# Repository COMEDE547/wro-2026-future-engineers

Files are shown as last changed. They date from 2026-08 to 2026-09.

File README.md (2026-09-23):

# WRO Future Engineers 2026 — Engineering Materials

Engineering documentation for an autonomous vehicle built for the **World Robot
Olympiad Future Engineers** category, season **2026**.

> **Team:** TED drive · **Members:** Ethan Fernandes (software) · Tejas Sirikonda (mechanical) · Deeyan Mehta (electronics) · **Coach:** Amey Chavan (OMOTEC) · **Country:** India

> **Vehicle status (2026-09-22):** the car was rebuilt in September for APAC 2026; what changed is in [`docs/apac_2026_vehicle.md`](docs/apac_2026_vehicle.md), and the code it runs is in [`src/apac-2026/`](src/apac-2026/). The At-a-glance table and documents 1–5 below describe the Nationals (August 2026) configuration.

**Contents:** [At a glance](#at-a-glance) · [Documentation index](#documentation-index) · [Repository layout](#repository-layout) · [Quick start](#quick-start) · [Competition artifacts](#competition-artifacts) · [Version history](#version-history) · [Known limits](#known-limits) · [Licence](#licence)

---

## At a glance

| | |
|---|---|
| **Architecture** | Two processors. ESP32 runs sensing and steering at ~50 Hz (nominal; effective rate unmeasured); Raspberry Pi 5 runs pillar detection. A stalled detector cannot stall the steering loop. |
| **Steering** | Single-servo Ackermann, 64-136 deg travel about a 106 centre (asymmetric, mat-tuned 2026-08-10), proportional on heading error at 1.0 servo-deg/deg with a 2 deg deadband — saturating at 42/30 deg of error |
| **Heading** | BNO055 absolute yaw. Corner detection is a *rising-edge* test on a side TF-Luna crossing 150 cm |
| **Range sensing** | 3x TF-Luna behind a PCA9548A I2C multiplexer (all three share address `0x10`) |
| **Pillar detection** | **Calibrated-Lab colour picker** — one (a,b) chroma disc per colour, sampled at the venue; the prior neural stack was superseded 2026-08-05 |
| **Why the neural stack lost** | `nanodet_lite` val decision accuracy **0.941** did not transfer to real footage — single-session, zero-clutter training data (a limit stated at training time, then observed) |
| **Validation** | 473 / 124 group-wise split, leakage-audited. 597 source images, **one lighting session**. |
| **Open Challenge** | Implemented — driven on the mat 2026-08-08/09 (test footage in [`other/`](other)); steering-sign fix + retune landed 2026-08-10 |
| **Obstacle Challenge** | ~~Implemented off-repo~~ **In-repo since 2026-08-06/07** — [`round2.py`](src/Round%202/round2.py) + [`main.cpp`](src/Round%202/main.cpp); radio compile-gated off (§11.10), I2C map verified (BNO on mux ch4) |
| **Drivetrain** | **Built and driven (final chassis — rebuild cancelled 2026-08-10)** — N20 via TB6612 through a LEGO differential; Ackermann steering. Pinion:crown counted 2026-08-11 (20:28 = 5:7); working-point currents still unmeasured. |

---

## Documentation index

Organised against the five criteria WRO uses to score engineering documentation.

| # | Criterion | Document | State |
|---|---|---|---|
| 1 | Mobility & Mechanical Design | [`docs/1_mobility.md`](docs/1_mobility.md) | Steering + drive integrated, driven on the mat, retune 2026-08-10 documented; **chassis final (rebuild cancelled 2026-08-10)**; pinion:crown counted 2026-08-11 on the vehicle: 20:28 = 5:7 |
| 2 | Power & Sensor Architecture | [`docs/2_power_and_sensors.md`](docs/2_power_and_sensors.md) | Sensors and camera geometry documented; **power budget partly measured** (pack voltage 2026-08-12, cruise current 2026-08-24; per-rail currents not yet) |
| 3 | Software Architecture & Obstacle Strategy | [`docs/3_software.md`](docs/3_software.md) | Open implemented (drives); Obstacle implemented, **in-repo since 2026-08-06/07**; Nationals competition stack at [`src/Round 2/competition/`](src/Round%202/competition/) since 2026-08-24; APAC 2026 code at [`src/apac-2026/`](src/apac-2026/) since 2026-09-22 |
| 4 | Systems Thinking & Engineering Decisions | [`docs/4_systems_and_decisions.md`](docs/4_systems_and_decisions.md) | Decision log, rejected alternatives, risk register |
| 5 | Reproducibility & Repository Quality | [`docs/5_reproducibility.md`](docs/5_reproducibility.md) | Reproduction steps, licensing, versioning policy |
| — | **APAC 2026 vehicle (September rebuild)** | [`docs/apac_2026_vehicle.md`](docs/apac_2026_vehicle.md) | Changes since Nationals, bench measurements (2026-09-21) and the code in [`src/apac-2026/`](src/apac-2026/); six-view photos, a full Obstacle Challenge run on video and the car's own test logs in [`docs/apac_2026_test_logs.md`](docs/apac_2026_test_logs.md) |
| — | **APAC 2026 software (Obstacle Challenge)** | [`docs/apac_2026_software.md`](docs/apac_2026_software.md) | State diagrams of `main.py`, the thresholds on each transition, why the states are split this way, edge cases and known limits |
| — | **Engineering Journal (APAC 2026)** | [`docs/engineering_journal_apac_2026.pdf`](docs/engineering_journal_apac_2026.pdf) | 26 pp; the APAC vehicle, built from this repository's documents by [`docs/journal/build_apac_journal.py`](docs/journal/build_apac_journal.py). The Nationals journal is the next row |
| — | **Engineering Journal (final, rev 3)** | [`docs/engineering_journal_final.pdf`](docs/engineering_journal_final.pdf) | 26 pp; describes the Nationals (August 2026) competition configuration; matches the repository at `b715a4b` |
| — | Testing workflow | [`docs/tests.md`](docs/tests.md) | T1-T4 running; T5-T7 blocked on hardware |
| — | Detector reference | [`src/Round 2/detector/README.md`](src/Round%202/detector/README.md) | Results, operating point, reproduction |
| — | Firmware reference | [`src/README.md`](src/README.md) | Sketch-by-sketch |

**Start with [4 — Systems Thinking](docs/4_systems_and_decisions.md)** if you only
read one. It carries the decision log, including the alternatives that were built
and rejected and the numbers that killed them.

---

## Repository layout

```
docs/           five criterion documents + testing workflow + figure scripts
src/Round 1/    ESP32 firmware — heading hold, corner detection, steering
src/Round 2/    flight stack (round2.py + main.cpp + eval harness) + superseded detector (kept as evidence) + classical HSV pipeline
models/         CAD / printable parts        — team STLs (TF-Luna enclosure, steering horn, N20 clamp) + current chassis LEGO design + 69-step build instructions; third-party mounts cited, not redistributed
schemes/        electromechanical schematics — signal + power wiring v0.2 (generated)
t-photos/       team photos                  — official team photo present (Ch.7 requires one)
v-photos/       vehicle photos               — 6 views, refreshed 2026-08-11 (redesigned frame, Pi + camera mounted); APAC 2026 six views in apac-2026-09-22/
video/          performance video links      Open 33 s + Obstacle 100 s (YouTube); APAC Obstacle run (mp4)
other/          datasheets, setup notes
```

Empty directories are empty because the artifact does not exist yet, not because
it was overlooked. Each one says which.

---

## Quick start

**Run the superseded neural detector (kept runnable as iteration evidence):**

```bash
cd "src/Round 2/detector"
python decide_nanodet.py --camera 0 --window 5     # prints "left" or "right"
python decide_nanodet.py --image frame.jpg
python decide_nanodet.py --sweep                   # re-derive the operating point
```

**Reproduce every number in this repository from scratch:**
see [`docs/5_reproducibility.md`](docs/5_reproducibility.md#3-reproducing-the-detector-from-zero).

**Build and flash the firmware:** Arduino IDE or PlatformIO, board = ESP32.
Libraries: Adafruit BNO055, Adafruit Unified Sensor, Adafruit BusIO, ESP32Servo.

---

## Competition artifacts

| Artifact | Required | Status |
|---|---|---|
| 6 vehicle photos — every side, top and bottom | Yes | **Present** — Nationals vehicle: `v-photos/` (2026-08-11, redesigned frame with Pi 5 and camera); APAC 2026 vehicle: [`v-photos/apac-2026-09-22/`](v-photos/apac-2026-09-22/) (2026-09-22, six views, side rollers removed). The 2026-08-11 set replaced a 2026-08-05 set that showed the pre-redesign chassis |
| Team photo | Yes | **Present** — `t-photos/team_photo_official.jpg`. Chapter 7 requires "a team photo" (singular); the informal second photo, a template convention rather than a rule, is `t-photos/team_photo_informal.jpg` |
| Performance video, >= 30 s autonomous driving, one per challenge | Yes | **Present**: Open Challenge 33 s and Obstacle Challenge 100 s on YouTube, in [`video/video.md`](video/video.md); additional footage of the APAC vehicle (a full Obstacle Challenge run, 3 min 19 s) in the same folder |
| Electromechanical schematic | Yes | **Present** — signal + power wiring v0.2 in `schemes/` (generated by a committed script; remaining unknowns drawn as TBD) |
| Control software | Yes | Present, `src/` |
| CAD / printable parts | Yes | **Present 2026-08-11/12** — team STLs (TF-Luna enclosure ×3-printed, steering horn, N20 clamp) + the **current chassis LEGO design file** and its 69-step build instructions in `models/chassis/`; camera-mount kit is third-party, cited not redistributed; MG90 is LEGO-integrated (no printed mount); no chassis STL because the redesign was in LEGO, not print (see D8) |

The pending rows are tracked here so the gap is visible rather than discovered
late.

---

## Version history

| Version | Date | Change | Problems it created or exposed |
|---|---|---|---|
| — | 2026-06-26 | Initial repo; ESP32 firmware — IMU heading hold, TF-Luna corner detection, ultrasonic prototype | Corner detection needed a rising-edge test; a level test re-fires and spins the vehicle |
| — | 2026-07-19 | HSV pillar pipeline v4.1, 0.43 ms/frame | Measured to fail in **both** directions, which voided the planned ROI-verifier fallback |
| — | 2026-07-26 | Trained NanoDet-Plus detector; vision moved under `Round 2` | Validation split found contaminated — 25 duplicate stems, 27/29 shared capture buckets. All prior numbers withdrawn and re-measured on a clean 473/124 split. |
| — | 2026-07-28 | Documentation restructured against the five scoring criteria | Root README had described the vehicle as camera-free after the detector had shipped |
| — | 2026-08-05 | Drive integrated (N20 / TB6612, append-only); calibrated-Lab picker declared the Round 2 stack; NanoDet superseded after field testing; signal-wiring schematic v0.1 added | The val-split winner did not survive real footage — the single-session dataset limit, stated at training time, was observed in practice |

Full reasoning for each entry: [`docs/4_systems_and_decisions.md`](docs/4_systems_and_decisions.md).

---

## Known limits

Stated here rather than left for a reader to find.

- **Every detector number rests on 597 images from a single lighting session**,
  with no other robots, spectators, banners or reflective flooring present. The
  figures are indicative, not a venue prediction — and field testing subsequently
  observed exactly this transfer failure (see the version history).
- **Both-pillar figures are synthetic composites.** No real image in the dataset
  contains a red and a green pillar at once.
- **No Raspberry Pi 5 latency figure exists for this model.** It will not be
  quoted until `benchncnn` has run on the target board.
- ~~**The Obstacle Challenge controller is not yet in this repository.** It is
  implemented and bench-tested off-repo; it lands after integration fixes.~~
  **Landed 2026-08-06/07** (`src/Round 2/round2.py` + `main.cpp`); this bullet
  was stale until 2026-08-10. [`docs/3_software.md`](docs/3_software.md) remains
  the specification of record.
- **The camera is a USB UVC webcam** — a **Lenovo 300 FHD** (read off the unit 2026-08-11; **OMO/WCAM/11** is the team's label for it, first recorded
  2026-08-08); field-of-view and angular-resolution figures are still pending a
  checkerboard measurement, so none is quoted.
- ~~**The vehicle is built to Round-1 configuration.** The Raspberry Pi 5 and camera are not yet mounted.~~ Stale since 2026-08-11, when both were mounted (six-view photos).
  Drive bring-up (direction, duty, corner tests)
  ~~is unfinished~~ happened 2026-08-08/09; the chassis is final (rebuild
  cancelled 2026-08-10). That was the Nationals car; it was rebuilt for APAC 2026
  ([`docs/apac_2026_vehicle.md`](docs/apac_2026_vehicle.md)).

---

## Licence

MIT — see [`LICENSE`](LICENSE). `src/Round 2/detector/nanodet_lite/` is a
derivative of [NanoDet](https://github.com/RangiLyu/nanodet) and is Apache-2.0;
its licence is at `src/Round 2/detector/LICENSE-nanodet-Apache-2.0`.

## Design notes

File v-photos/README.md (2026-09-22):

# Vehicle photos

Six views as required by chapter 7 — every side, plus top and bottom — of the
vehicle **as it ran at Nationals**, photographed 2026-08-11. Working photos of the
September rebuild for APAC 2026 are in [`apac-2026-09-20/`](apac-2026-09-20/); the
six-view set of the APAC vehicle (received 2026-09-22) is in
[`apac-2026-09-22/`](apac-2026-09-22/) (table below).

| File | View | What it shows |
|---|---|---|
| `vehicle-front.jpg` | Front | Camera on its printed arm, the centre TF-Luna behind its orange bracket, front wheels (41 × 21 mm) |
| `vehicle-rear.jpg` | Rear | Electronics deck from behind, rear wheels (55.6 × 14 mm) through the differential |
| `vehicle-left.jpg` | Left | Full profile, nose to frame-right — deck height, camera standoff, side TF-Luna |
| `vehicle-right.jpg` | Right | Full profile, nose to frame-left |
| `vehicle-top.jpg` | Top | ESP32, buck converter, PCA9548A multiplexer and BNO055 on the deck |
| `vehicle-bottom.jpg` | Bottom | LEGO differential, drive shaft from the N20 pinion, steering linkage |
| `detail/` | — | Two close-ups: chassis mid-section, and the front sensor + camera mount |

Note on labels: in this set, `vehicle-left.jpg` shows the nose to frame-right,
which by the usual convention is the car's right side, and `vehicle-right.jpg`
shows its left side. The APAC photos in `apac-2026-09-20/` use the usual
convention.

## These replaced an earlier set, and why

The previous six photos were taken **2026-08-05** and showed the vehicle before
the chassis was redesigned. The wheel-shed failure of 2026-08-06 was answered by
a ground-up redesign of the LEGO space-frame — stiffer than the first layout —
and every run and every committed artifact since 2026-08-09 is on that frame
([1 — Mobility](../docs/1_mobility.md) §3,
[D8](../docs/4_systems_and_decisions.md)). Photographs of a superseded frame
would have described a vehicle that no longer exists, so they were replaced
rather than kept.

The 2026-08-05 set also predated the Pi 5 and camera being mounted; both are
fitted and visible here.

## APAC 2026 six-view set (2026-09-22)

The rebuilt vehicle ([APAC 2026 vehicle](../docs/apac_2026_vehicle.md)), photographed on
the team's practice mat after the horizontal side rollers were removed (photos
received 2026-09-22; §7 there). Usual convention: `apac-left.jpg` is the car's left side, nose to frame-left.

| File | View | What it shows |
|---|---|---|
| `apac-2026-09-22/apac-front.jpg` | Front | Camera on the rear tower, the WS2812 strips on the front frame, the centre TF-Luna in its orange bracket, front wheels |
| `apac-2026-09-22/apac-rear.jpg` | Rear | The tower from behind, the power switch, rear wheels |
| `apac-2026-09-22/apac-left.jpg` | Left | Full profile, nose to frame-left |
| `apac-2026-09-22/apac-right.jpg` | Right | Full profile, nose to frame-right |
| `apac-2026-09-22/apac-top.jpg` | Top | Camera housing over the deck, ESP32 board and breakouts, rear wheels |
| `apac-2026-09-22/apac-bottom.jpg` | Bottom | Underside with the car laid on its side: both axles and the drive motor |

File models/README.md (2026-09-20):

# models/ — CAD for TED drive (WRO FE 2026)

The vehicle is a **LEGO Technic chassis**; every non-LEGO component is held by a
3D-printed bracket. This folder holds the team's own design files and printable
parts. Third-party parts used on the vehicle are attributed below and NOT
redistributed here.

## Chassis — APAC 2026 frame (September rebuild)

| File | What it is |
|---|---|
| `chassis/chassis_build_instructions_apac_2026-09.pdf` | 84-step build instructions for the frame used at APAC 2026. LEGO parts only; the printed parts are the same STL files as at Nationals (listed below). |

What changed since Nationals: [`docs/apac_2026_vehicle.md`](../docs/apac_2026_vehicle.md).

## Chassis — Nationals frame (August 2026)

| File | What it is |
|---|---|
| `chassis/chassis_lego_current.lxfml` | The LEGO design for the frame the vehicle ran at Nationals — 91 elements, 19 distinct part types |
| `chassis/chassis_build_instructions.pdf` | 69-step build instructions generated from that model, enough to rebuild the frame from parts |

**This was the redesigned Nationals frame, not the superseded first layout.** The first layout could
not package motor and battery together, carried its mass too high, and would not
hold a curve; under drive load it also flexed enough to work the rear axle
interface loose, and the wheels shed within seconds on 2026-08-06. The answer was
a ground-up redesign of the space-frame, built stiffer — the frame documented
here. It ran 28 s and 29 s with no wheel loss on 2026-08-09, roughly six times
the failure duration, and the planned 3D-printed rebuild was cancelled as
unnecessary. Full account: [1 — Mobility](../docs/1_mobility.md) §3 and
[D8](../docs/4_systems_and_decisions.md).

Because the answer was a LEGO redesign rather than a printed one, the chassis
artifact here is a design file and a build sequence rather than a chassis STL.
There is no printed chassis and there never was.

## Team-designed printed parts (Nationals vehicle, as fitted 2026-08-11)

| Part | File | Fitted as | Bounding box (mm) | Designed by / in |
|---|---|---|---|---|
| TF-Luna holder | `tf-luna/TF_luna_enclosure_lego.stl` | LEGO-pitch face frame for a TF-Luna (56 mm = exactly 7 LEGO modules; printed 3×, orange PLA) | 9.0 × 56.0 × 26.3 | TED drive, Fusion 360 |
| Servo horn beam, long | `steering/Horn_Beam_LONG.stl` | MG90S horn → LEGO beam steering link | 45.5 × 11.8 × 7.8 | TED drive, Fusion 360 |
| N20 motor mount | `drive/n20_clamp_lego.stl` | Printed clamp holding the 12 V N20 gearmotor to the LEGO frame | 38.8 × 26.0 × 12.0 | TED drive, Fusion 360 (re-modelled; .f3d export still owed) |

Parametric sources: Fusion 360 — **export and commit the .f3d/.step for each
team part alongside its STL** (Fusion cloud retains them).

## Third-party printed parts — sources

The Lenovo 300 FHD webcam is held by four printed parts of a published mount
kit. The kit's files are linked, not redistributed, in this repository — that
is safe under every possible license, and attribution is the requirement
either way.

**[1]** cncplasticfactory, *"Lenovo 300 FHD Webcam Mount for 3D Printers with
2020 Extrusions,"* Printables.com, model 352447, updated 29 Dec 2022.
https://www.printables.com/model/352447 — accessed 11 Aug 2026.
Parts as fitted on the vehicle: front clamp, rear clamp, base bracket, spacer
arm (white PLA). License: stated on the model page (not machine-readable at
citation time) — confirm there before ever redistributing the files.
Parts used as-printed from the published geometry; no modifications.

**[2]** PsychoShaft, *"C92X Mount,"* VoronDesign/VoronUsers `printer_mods`
(the upstream design that [1] remixes).
https://github.com/VoronDesign/VoronUsers/tree/master/printer_mods/PsychoShaft/C92X_PsycHoShafts_Mount
— lineage credit only; no files taken from it directly.

**[3]** Lenovo, *"Lenovo 300 FHD WebCam — Overview and Service Parts,"*
acc500192.
https://support.lenovo.com/in/en/accessories/acc500192-lenovo-300-fhd-webcam-overview-and-service-parts
— the mounted camera hardware (1080p, 95° FOV, USB). Team designation for the
same unit: **OMO/WCAM/11** (see `docs/2_power_and_sensors.md`).

## Not printed

MG90S servo body is LEGO-integrated. The N20 sits in the printed clamp above;
the .f3d source for it is still owed.

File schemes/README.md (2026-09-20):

# Electromechanical schematics

**Current: [`wiring_apac_2026.md`](wiring_apac_2026.md)** — power and signal wiring of the September 2026 rebuild for APAC 2026 (WS2812 LEDs on GPIO4, power switch on the battery lead, start button on GPIO32, MEX drive motor), drawn as a Mermaid diagram that GitHub renders. The files below describe the Nationals (August 2026) vehicle.

**`wiring-v0.2.png` / `.pdf` — signal-wiring authority (2026-08-10); its power
tree is HISTORICAL, superseded by the 2026-08-11 rework recorded in the hand
diagram below.** Everything v0.1 drew, plus the power tree as identified on
2026-08-10: 3S 11.1 V pack (label read 2026-08-11: **2200 mAh 60C** — the
frozen v0.2 render predates the read and shows 2600) -> dual-rail buck
(barrel-jack in; XL4015/LM2596-class, chip and rating TBD; 5 V screw out +
USB-A out) -> ESP32 VIN, with the servo drawn through the ESP32's 5 V chain
(the named brownout risk in [docs/2 §5](../docs/2_power_and_sensors.md) —
**fixed 2026-08-11**: servo power moved to Buck-2; the v0.2 render predates
the rework), pack 11.1 V direct to TB6612 VM, and the buck's USB-A drawn as the
**candidate** Pi 5 supply — TBD, because a plain USB-A source has no PD
negotiation, which makes the Pi 5 cap its USB-peripheral budget at 600 mA.
Unknowns are drawn as TBD rather than guessed. The missing rule-9.10-mandatory
main power switch and the absent fuse are called out on-sheet.

The diagram is generated, not hand-drawn: edit
[`make_wiring_v0_2.py`](make_wiring_v0_2.py) and rerun
(`py -3 schemes/make_wiring_v0_2.py` from the repo root, needs matplotlib) —
do not edit the PNG.

**`wiring-signal-v0.1.png` / `.pdf`** — superseded 2026-08-10, retained as
history. Signal wiring only; left the power tree as "pending battery selection"
(the pack was read off the hardware on 2026-08-06) and carried a CH4-vs-CH5
BNO055 harness question that closed when the Round 2 firmware landed on
**CH4**.

**`circuit_diagram_complete_2026-08-11.jpg`** — full power + control diagram
(hand-drawn, photographed at the bench 2026-08-11). Companion to wiring-v0.2,
which remains the generated signal-wiring authority. Every firmware-relevant
pin on this diagram was cross-checked against `src/Round 2/main.cpp` the same
day and matched 6/6: I2C SDA/SCL `21/22`, servo `13`, TB6612 `25/26/33/27`,
PCA9548A `0x70` (channels 0/1/2 = TF-Luna `0x10`, CH4 = BNO055 `0x28`). It also
records the as-built power tree confirmed on the vehicle: servo **power** from
Buck-2 (signal only from the ESP32), 3× TF-Luna on Buck-2, ESP32 from a Pi USB
port, Pi via the fast-charging module — see `docs/2_power_and_sensors.md` §5/§6
for the rework note this supersedes. **Known omission:** the diagram does not
show the external start button on **GPIO32** that both firmwares use — the
button was wired after the diagram was drawn; treat GPIO32 as present per
`src/`.

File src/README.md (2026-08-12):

# Control software

Two rounds, two processors.

## `Round 1/` — ESP32 firmware

Compiles in the Arduino IDE or PlatformIO, board = **ESP32**. Each sketch sits in
its own folder, per Arduino IDE convention.

| Sketch | Role |
|---|---|
| `round 1/round 1.ino` | **Main driving firmware.** Captures a target heading from the BNO055, drives straight by proportionally counter-steering the servo to null heading error, and detects corners on the rising edge of a side TF-Luna crossing 150 cm (steps the target heading by 90 deg). Drives an N20 via TB6612 (append-only module): 20 kHz 10-bit PWM, observer turn counter, settle-gated 0.5 s run-on after 12 corners, then brake. Steering-sign fix + retune 2026-08-10 (`58adb1c`): center 106, limits 64/136, gain 1.0, DRIVE_SPEED 1000. |
| `motor_test/motor_test.ino` | Serial bring-up for the drive motor via `motor_control.h` (w/s speed steps, `r` reverse, `b` brake, `i` state). Pin constants matched to the main-firmware harness: PWM 33 · IN1 25 · IN2 26 · STBY 27. |
| `triple_ultrasonic_sensor/triple_ultrasonic_sensor.ino` | Standalone 3x HC-SR04 test (front / left / right), interrupt-driven and non-blocking. Alternative sensing prototype — see the LiDAR-vs-ultrasonic comparison in [`docs/2_power_and_sensors.md`](../docs/2_power_and_sensors.md#why-lidar-over-ultrasonic-for-corner-detection). |
| `GetAngle_IMU/GetAngle_IMU.ino` | Early MPU6050 read-out test. Superseded by the BNO055; retained because the reason for the switch is documented against it. |

**Libraries:** Adafruit BNO055, Adafruit Unified Sensor, Adafruit BusIO,
ESP32Servo (+ Adafruit MPU6050 for the legacy test).

**Key I/O (main sketch):** I2C `SDA = GPIO21` / `SCL = GPIO22` @ 400 kHz ·
servo signal `GPIO13` · PCA9548A mux `0x70` (ch0/1/2 = left/centre/right TF-Luna
@ `0x10`, ch4 = BNO055 @ `0x28`) ·
TB6612 AIN1 `GPIO25` / AIN2 `GPIO26` / PWMA `GPIO33` / STBY `GPIO27`.

**Drive-motor control: integrated (2026-08-03), append-only.** The original
steering / corner logic is byte-untouched; the module observes target-heading
steps rather than modifying trigger code. ~~Physical bring-up pending the build~~
**Driven on the mat 2026-08-08/09** (test footage under [`other/`](../other)) —
see [`docs/1_mobility.md`](../docs/1_mobility.md).

## `Round 2/` — perception, on the Raspberry Pi 5

| Path | Role |
|---|---|
| `round2.py` | **Pi 5 flight script.** Calibrated-Lab colour picker (venue calibration via `--calib` → `calib.json`), PyAV camera capture with v4l2 exposure/white-balance lock, temporal vote gate, and the serial command stream to the ESP32 (`RED`/`GREEN`/`CLEAR`/`REVERSE`/`POS,cx,h` on a stable `/dev/serial/by-id/*` path (`ttyUSB*`/`ttyACM*` fallback; headless mode exits hard with code 2 if no port opens — changed 2026-08-11) @ 115200, refreshed every 0.5 s against the controller's 1.5 s dead-man). |
| `main.cpp` | **ESP32 obstacle controller.** Heading capture at the start button, IMUPLUS yaw, PD steering with deadband and clamp, persist-gated corner spikes, visual-servo swerve on the Pi's command stream. Center/limits aligned to the Round-1 mat tune 2026-08-10 — bench-verify before flashing. |
| `eval_picker.py` | Measurement harness — imports `round2.py`'s detection functions verbatim (serial/camera stubbed) and re-derives the picker tables in [`docs/eval_raw/`](../docs/eval_raw). |
| `history/` | Prior code lineages, retained as iteration evidence. |
| [`detector/`](Round%202/detector/README.md) | Pillar detector. Stripped NanoDet-Plus, training loop, evaluation, operating-point sweep, ONNX export, deploy weights. **Superseded 2026-08-05 — kept as iteration evidence**; see the status banner in its README. |
| `vision/` | Classical HSV + connected-components pipeline, 0.43 ms/frame. Retained as a diagnostic and zero-dependency sanity check, not as the competition detector — reasoning in [`docs/4_systems_and_decisions.md`](../docs/4_systems_and_decisions.md#d1--neural-pillar-detector-deferred-then-adopted-the-same-day). |

~~The current Round 2 stack — calibrated-Lab colour picker + the ESP32 obstacle
controller — is implemented off-repo and lands after integration fixes.~~
**Corrected 2026-08-10: the stack has been in-repo since 2026-08-06/07**
(`round2.py` + `main.cpp` above); this paragraph was stale on the judged
surface. State machine and stack rationale:
[`docs/3_software.md`](../docs/3_software.md#2-obstacle-challenge--implemented).

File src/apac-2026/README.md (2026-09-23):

# APAC 2026 competition code

The code the vehicle runs at WRO Future Engineers APAC 2026: the Obstacle Challenge stack and the Open Challenge firmware. The vehicle is described in [`docs/apac_2026_vehicle.md`](../../docs/apac_2026_vehicle.md), and how `main.py` drives the run, with its state diagrams, in [`docs/apac_2026_software.md`](../../docs/apac_2026_software.md). The two parking modules are described in its [section 8](../../docs/apac_2026_software.md#8-parking-modules).

| File | Runs on | What it does |
|---|---|---|
| [`obstacle-challenge/main.py`](obstacle-challenge/main.py) | Raspberry Pi 5 | Camera, pillar and line detection, and the driving decisions; sends drive commands to the ESP32 |
| [`obstacle-challenge/parallel_parking.py`](obstacle-challenge/parallel_parking.py) | Raspberry Pi 5 | Parallel parking at the end of the run (`BUILD_ID = "slot-guided-entry-v29"`): finds the two parking-lot limitations with the camera, drives into the gap and straightens up. Imports `main.py`; called by `main.py` after the twelfth corner when `PARALLEL_PARKING = True`, or run on its own |
| [`obstacle-challenge/partial_parking.py`](obstacle-challenge/partial_parking.py) | Raspberry Pi 5 | Direct entry into the parking space on a locked heading, reusing the parallel module's approach and block search. Called by `main.py` after the twelfth corner when `PARTIAL_PARKING = True` (as committed), or run on its own |
| [`obstacle-challenge/esp32/obstacle-challenge-final-code/obstacle-challenge-final-code.ino`](obstacle-challenge/esp32/obstacle-challenge-final-code/obstacle-challenge-final-code.ino) | ESP32 | Drive motor, steering servo, LEDs, the three TF-Luna sensors and the BNO055 through the PCA9548A; sends telemetry to the Pi |
| [`open-challenge/open-challenge.ino`](open-challenge/open-challenge.ino) | ESP32 | The Open Challenge on the ESP32 alone: direction detection, wall following with heading hold, twelve 90° turns on the BNO055 heading, and a final stop at 150 cm from the wall ahead ([software §11](../../docs/apac_2026_software.md#11-open-challenge-firmware)) |
| [`obstacle-challenge/parking_camera_calibration.json`](obstacle-challenge/parking_camera_calibration.json) | Raspberry Pi 5 | The team's image-to-floor calibration for the parking modules (1280 × 720 image, 100 × 150 cm rectangle) |
| [`tools/lab-calibration.py`](tools/lab-calibration.py) | Pi or laptop | Interactive Lab colour-threshold picker (trackbars), with the same image preprocessing as `main.py`; how it is used at a venue is in [vehicle §4](../../docs/apac_2026_vehicle.md) |
| [`tools/camera-settings.py`](tools/camera-settings.py) | Pi or laptop | Interactive brightness, contrast and gamma preview |

## Serial link

115200 baud. `main.py` opens `/dev/ttyUSB0` on the Pi (`COM3` is its Windows bench setting).

- Pi to ESP32: `speed,direction,steer` and a newline. `speed` is the 8-bit PWM duty (0 to 255); `steer` is a correction of -60 to +60 around the servo centre of 85.
- ESP32 to Pi: telemetry lines `T,seq,ms,heading,left,center,right,validMask,hardStop,appliedSpeed`.

## Settings as committed

| Setting | Value | File |
|---|---|---|
| Drive speed | `SPEED = 215` (84 % duty) | `main.py` |
| Turning, parking, collision escape | `100`, `70`, `80` | `main.py` |
| Leave the parking area at the start | `ENABLE_PARKING_EXIT = True` | `main.py` |
| Park at the end | `ENABLE_PARKING_IN = True`: after the twelfth corner `main.py` hands over to a parking module, chosen by `PARTIAL_PARKING = True` and `PARALLEL_PARKING = False` as committed (exactly one must be on; [software §8](../../docs/apac_2026_software.md#8-parking-modules)) | `main.py` |
| Run log | `ENABLE_RUN_CSV_LOGGING = False`; set to `True`, every run writes `run_logs/round2_run_<date_time>.csv` beside `main.py`, one row per telemetry sample and one per event | `main.py` |
| Parking modules | run on their own, e.g. `python parallel_parking.py --direction clockwise --last-pillar auto` | `parallel_parking.py`, `partial_parking.py` |
| Parking run log (CSV and video per run) | `ENABLE_RUN_LOGGING = False` | `parallel_parking.py` |
| Servo centre | `SERVO_CENTER = 85` in the Obstacle firmware; 106 in the Open Challenge firmware | firmware |
| Mux channels | TF-Luna left 0, centre 3, right 2; BNO055 4 | firmware |
| Front hard stop | disabled since 2026-09-10 (`forwardHardStopIsActive()` returns `false`); see [vehicle §7](../../docs/apac_2026_vehicle.md) | firmware |

Both parking modules read `parking_camera_calibration.json` beside them. It depends on how the camera is mounted: the team's file, made on the practice mat with the September camera mount, is committed; `python parallel_parking.py --calibrate` makes a new one if the mount changes.

On the Pi, `main.py` sets GPIO3 high once it has initialised and is waiting for the start signal, and low when it exits.

## Provenance and checksums

The files come from the team's working copy of the code (the coach's repository, commit `63c2b31`, with the team's later changes) as of 23 September 2026. They are stored byte-for-byte (see [`.gitattributes`](.gitattributes)), so these MD5s can be checked on any checkout:

| File | MD5 |
|---|---|
| `main.py` | `77187817b99846d4c7d8766d5e9b8bf7` |
| `obstacle-challenge-final-code.ino` | `a0bf8c1ca5330442bed69d8299892572` |
| `lab-calibration.py` | `aad32eb3ca1954ad38683ee5a004da1a` |
| `camera-settings.py` | `f02e7f9eaae329e8867e965ac4f98511` |
| `parallel_parking.py` | `9d622df00da023df403fc06669c3c014` |
| `partial_parking.py` | `34bb36075c2ab680220bd6557056992a` |
| `open-challenge.ino` | `caf69d495f3d0f259a796dfcb81e5b5c` |
| `parking_camera_calibration.json` | `d2ebad50bf7a573496625ee7d20f26da` |

Not included, because none of them runs on this vehicle: the build without LEDs, the firmware and the Open Challenge variant for a smaller robot, backup copies, component tests, experiments (`main_backgroung_notworking.py`, `corner_slot_filler.py`, `parking_entry_only.py`, `parking_exit_only.py`, `cornering_sequence.py`) and the HSV and RGB colour tools.

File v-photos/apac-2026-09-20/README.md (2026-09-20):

# APAC 2026 vehicle — working photos, 2026-09-20

Taken on the practice mat during testing, with USB and power cables still attached. These are not the race-ready set: six views (front, back, left, right, top, bottom) of the vehicle in race trim will replace them.

| File | View |
|---|---|
| `apac-front.jpg` | Front: WS2812 strips on the front frame, front TF-Luna, steering column |
| `apac-rear.jpg` | Rear: camera tower |
| `apac-left.jpg` | Left side (nose to frame-left) |
| `apac-right.jpg` | Right side (nose to frame-right) |
| `apac-top.jpg` | Top (out of focus) |
| `apac-front-quarter.jpg` | Front three-quarter |

What changed since Nationals: [`docs/apac_2026_vehicle.md`](../../docs/apac_2026_vehicle.md). The Nationals (August 2026) six-view set is in the [parent folder](../).

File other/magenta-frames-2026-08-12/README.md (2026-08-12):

# Magenta parking-marker frames — 2026-08-12

Source footage for the magenta measurements quoted in
[`docs/3_software.md`](../../docs/3_software.md) §3.1 and §4.2. Committed so the
numbers can be checked against the images that produced them, rather than taken
on trust.

## Provenance

Two phone videos of the improvised parking-lot markers on the OMOTEC practice
mat, shot by the team on 2026-08-12 (832×464, 60 fps). Every 20th frame was
extracted with [`cut_frames_2026-08-12.py`](../../src/Round%202/detector/tools/cut_frames_2026-08-12.py),
giving **85 frames** (`vidA_*` 39, `vidB_*` 46). One extra file,
`vidB_f00200_det.jpg`, is a detector overlay kept as a visual sanity check.

Labels are YOLO-format, **132 boxes across 85 frames**, class id `2`.
`classes.txt` preserves the project-wide order `green / red / magenta` — the
same order as `data.yaml`, so a config read against a different order inverts
every class. That ordering trap is why the file is committed alongside the
labels rather than assumed.

## What these frames measured

Run [`magenta_lab_stats.py`](../../src/Round%202/detector/tools/magenta_lab_stats.py)
over this folder to reproduce:

| Quantity | Value |
|---|---|
| Magenta Lab centre | a\* +55, b\* −16 (b\* MAD 2.0) |
| Separation from red in the (a,b) plane | **46.8 (stills) / 55.1 (video)** |
| Calibration tolerance cap | 15 (red↔green), 22 (magenta) |
| Magenta detection through full `process_frame` | **43/85 → 76/85** at tolerance 20 |

The separation figure is the point: at a tolerance of 15–22 against a measured
neighbour distance of 46.8–55.1, red/magenta confusion is **structurally
impossible on real footage**, not merely unlikely. That claim previously rested
on published RGB values; these frames are the measured form of it.

Magenta is also the only one of the three classes with **b\* < 0**, which the
picker uses as a free hard pre-gate (mirroring the `b* > 0` gate on red).

## Honest limits

- **One session, one venue, one phone.** Not the race camera, and not venue
  lighting.
- **Auto white balance drifted** between the two clips — measured a\* moved
  60 → 49 across 22 seconds. These frames are therefore good for tuning gates
  and bad as an absolute colour reference; the race procedure remains a live
  locked-camera calibration at the venue (key `3`).
- The **9 residual misses** are all close-approach frames where chroma
  physically collapses as the marker fills the frame. That range belongs to the
  forward TF-Luna by design, not to the colour picker. Distant and mid-range
  detection is 100%.
- Labels were auto-generated then reviewed, not hand-drawn from scratch.

## Related

`src/Round 2/detector/` holds the 3-class model trained partly on this data
(`pillar_3class_yolo26n_320.onnx`, in-domain mAP50-95 green .859 / red .792 /
magenta .820) together with `wro_3class_train.ipynb`. That model is committed
**NOT DEPLOYED** — the calibrated-Lab picker remains the stack of record until
`benchncnn` and a concurrent-load test on the Pi 5 say otherwise.

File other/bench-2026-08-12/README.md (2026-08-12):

# Bench session — 2026-08-12 (OMOTEC)

Voltage-only measurement session, Fluke 15B+ (DC-V autorange), 14 photos.
ESP32 was running `sketch_aug12c.ino` (serial motor-test, visible in-frame)
via laptop USB; wheels off ground; Pi state not recorded — NOT the as-raced
condition the power budget specifies. Values feed
`docs/2_power_predicted_budget.md` (row 1; footnote).

Readings:
- Pack / VIN: **12.47–12.49 V** (photo 03 also shows the pack label —
  Champion **2200 mAh 60C** — the capacity read of 2026-08-11, photo-backed).
- 5 V node: **5.05–5.08 V** (photo 07). Probe point not conclusively
  identifiable as Buck-2 output vs the Pi-USB 5 V feeding the ESP32; both
  nodes read ~5.0–5.1 V, so this number is deliberately NOT entered as the
  row-4 Buck-2 measurement.
- Motor terminals at 0 / half / full commanded speed: 0 / 5.95–5.96 /
  12.47 V — PWM duty-cycle means (~0 / 48 / 100 %), not rail voltages.

Excluded as artifacts: 1.248 / 0.506 / 0.595 V frames — the same digits
decade-shifted (autorange transition / probe-contact flake).

Not measurable with this meter: all currents (voltage-only), servo transient
dip (no MIN capture). Those rows stay empty until a better meter surfaces.

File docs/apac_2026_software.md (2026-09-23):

# APAC 2026 software - Obstacle Challenge state machine

**Scope.** How the Obstacle Challenge code in [`main.py`](../src/apac-2026/obstacle-challenge/main.py) works: the control loop and the run (§1–§6), validation (§7), the parking modules (§8), pillar and line detection (§9), staying off the walls (§10) and the Open Challenge firmware (§11). Names in capitals are states; names in `code` are constants, given with their values.

## 1. The control loop

In a loop that sleeps 10 ms between passes (`NAVIGATION_LOOP_SECONDS`), the Raspberry Pi:

1. reads the newest ESP32 telemetry line: heading, the left, centre and right TF-Luna distances, and a validity mask;
2. takes the newest camera frame, masks its sides and runs the pillar and tape-line detector (`UnifiedPillarDetector`, §9);
3. calls the controller (`ObstacleChallengeController.update`), which sends one `speed,direction,steer` command to the ESP32.

The run starts once the start button has been held for 2 s: the ESP32 then sends `OK` and the Pi answers `OK`. The car leaves the parking lot (`ENABLE_PARKING_EXIT = True`), drives three laps and, after the twelfth corner (`COUNTER_MAX = 12`), hands over to a parking module (PARKING_PARALLEL_HANDOFF, §8). Every state change is printed as `[NAV] OLD -> NEW: reason`, and logged when `ENABLE_RUN_CSV_LOGGING = True` (§7).

## 2. The run

The diagrams in this section and in §3 show the transitions the car took in its logged runs of 19–22 September (89 runs, §7); the labels paraphrase the reasons the code prints.

**Leaving the parking lot.**

```mermaid
stateDiagram-v2
    direction TB
    [*] --> PARKING_EXIT_DIRECTION : start button held 2 s
    PARKING_EXIT_DIRECTION --> PARKING_EXIT_ARC_1 : side walls give the direction
    PARKING_EXIT_ARC_1 --> PARKING_EXIT_ARC_2 : heading 10°
    PARKING_EXIT_ARC_2 --> PARKING_EXIT_ARC_3 : reverse arc to 25°
    PARKING_EXIT_ARC_3 --> PARKING_EXIT_FORWARD_ALIGN : 35°
    PARKING_EXIT_FORWARD_ALIGN --> PARKING_EXIT_REVERSE_VIEW : heading within 8°
    PARKING_EXIT_FORWARD_ALIGN --> FAULT : 4.5 s without alignment
    PARKING_EXIT_REVERSE_VIEW --> FOLLOW_STRAIGHT : lane heading set
    PARKING_EXIT_REVERSE_VIEW --> PARKING_EXIT_SCAN : 2 s reverse, pillar check
    PARKING_EXIT_SCAN --> PARKING_EXIT_CW_RETURN_1 : green or no pillar
    PARKING_EXIT_SCAN --> PARKING_EXIT_TIMED_CURVE : red on the turning side
    PARKING_EXIT_CW_RETURN_1 --> PARKING_EXIT_CW_RETURN_2 : 30°
    PARKING_EXIT_CW_RETURN_2 --> PARKING_EXIT_COMPLETE : 0°
    PARKING_EXIT_COMPLETE --> FOLLOW_STRAIGHT
    PARKING_EXIT_TIMED_CURVE --> PARKING_EXIT_RED_REVERSE : front close to the pillar
    PARKING_EXIT_RED_REVERSE --> PARKING_EXIT_RED_FORWARD : reverse done
    PARKING_EXIT_RED_FORWARD --> PARKING_EXIT_SHARP_RETURN : 0.5 s forward
    PARKING_EXIT_SHARP_RETURN --> FOLLOW_STRAIGHT : lane heading reached
```

An anticlockwise start mirrors the lane return (PARKING_EXIT_ANTI_RETURN_1 and _2).

**Three laps.**

```mermaid
stateDiagram-v2
    direction TB
    FOLLOW_STRAIGHT --> ACQUIRE_PILLAR : pillar in view
    ACQUIRE_PILLAR --> PASS_RED_RIGHT : red, 3 of 5 frames
    ACQUIRE_PILLAR --> PASS_GREEN_LEFT : green, 3 of 5 frames
    ACQUIRE_PILLAR --> FOLLOW_STRAIGHT : not confirmed in 1.2 s
    PASS_RED_RIGHT --> CONFIRM_PASSED : pillar leaves the view
    PASS_GREEN_LEFT --> CONFIRM_PASSED : pillar leaves the view
    CONFIRM_PASSED --> PILLAR_RECENTER : pillar cleared
    PILLAR_RECENTER --> FOLLOW_STRAIGHT : back on the lane centre
    PILLAR_RECENTER --> APPROACH_CORNER : corner geometry locked
    FOLLOW_STRAIGHT --> APPROACH_CORNER : corner geometry locked
    APPROACH_CORNER --> TURN_90 : end wall close
    APPROACH_CORNER --> FOLLOW_STRAIGHT : 3 s without a corner
    TURN_90 --> TURN_90 : reverse blocked, forward arc
    TURN_90 --> POST_TURN_BACKUP : new heading reached
    POST_TURN_BACKUP --> POST_TURN_SCAN_HOLD : 0.35 s reverse
    POST_TURN_SCAN_HOLD --> ACQUIRE_PILLAR : pillar in view
    POST_TURN_SCAN_HOLD --> RECENTER : 0.2 s, no pillar
    RECENTER --> FOLLOW_STRAIGHT
    TURN_90 --> PARKING_PARALLEL_HANDOFF : twelfth corner
    PARKING_PARALLEL_HANDOFF --> [*] : parking module
```

- Red pillars are passed on the right and green ones on the left. If the pillar is still in view after CONFIRM_PASSED, the car returns to its pass state.
- At most two pillars are taken on each straight (`MAX_PILLARS_PER_STRAIGHT = 2`); a pillar seen beyond both tape lines within 5 s of a pass (`ALPHA_POSITION_WINDOW_SECONDS`) belongs to the next straight, so the corner is taken first.
- Every driving state brakes and holds while the telemetry is older than 0.30 s (`TELEMETRY_STALE_SECONDS`), a TF-Luna or the heading is invalid, or the camera frame is older than 0.30 s (`CAMERA_STALE_SECONDS`). It resumes in the same state, and the hold does not count against that state's timers.

## 3. Recovery and faults

```mermaid
stateDiagram-v2
    direction TB
    state "FOLLOW_STRAIGHT, APPROACH_CORNER or PILLAR_RECENTER" as DRIVING
    state "ACQUIRE_PILLAR or a PASS state" as PILLAR
    DRIVING --> HARD_STOP_RELEASE : front at 5 cm
    HARD_STOP_RELEASE --> REASSESS_FRONT : short reverse done
    HARD_STOP_RELEASE --> DRIVING : latch released
    HARD_STOP_RELEASE --> DEEP_REVERSE_RECOVERY : pillar release incomplete
    REASSESS_FRONT --> FOLLOW_STRAIGHT : front clear
    REASSESS_FRONT --> APPROACH_CORNER : corner geometry restored
    REASSESS_FRONT --> ACQUIRE_PILLAR : pillar in view
    REASSESS_FRONT --> HARD_STOP_RELEASE : still close
    REASSESS_FRONT --> CORNER_CLEARANCE_RECOVERY : at a corner, up to 3 attempts
    CORNER_CLEARANCE_RECOVERY --> REASSESS_FRONT : 30 cm reached
    REASSESS_FRONT --> FAULT : corner reverse made no progress
    PILLAR --> EMERGENCY_ESCAPE : front at 5 cm
    EMERGENCY_ESCAPE --> PILLAR : front improved
    EMERGENCY_ESCAPE --> DEEP_REVERSE_RECOVERY : 2 pulses, little progress
    DEEP_REVERSE_RECOVERY --> REASSESS_FRONT : clearance or time limit
    FAULT --> [*] : brake for the rest of the run
```

EMERGENCY_ESCAPE reverses for 0.3 s at speed 80 and resumes the state it interrupted once the front has improved by at least 3 cm (`EMERGENCY_ESCAPE_*`); after 2 pulses without that progress, DEEP_REVERSE_RECOVERY reverses at speed 75 for 0.6 to 0.8 s, aiming for 70 cm of clearance (`DEEP_RECOVERY_*`). HARD_STOP_RELEASE backs off until the front reads 30 cm (`HARD_STOP_RELEASE_CM`).

The code prints a reason with every FAULT: the turn could not reach its target after retries; the ESP32 did not report an applied reverse; the corner-clearance reverse made no reliable progress; both side walls were too close for a corner reverse; in the parking exit, the forward heading alignment timed out (4.5 s), the red approach took more than 4 s, or the timed return did not reach its heading within 5 s.

## 4. Why the states are split this way

| State | Reason |
|---|---|
| PARKING_EXIT_DIRECTION | The lane direction must be known before the first corner. The code takes it from which side wall is nearer: 7 of the last 9 readings must agree, each with left and right at least 15 cm apart (`DIRECTION_MIN_DIFFERENCE_CM`). |
| PARKING_EXIT_ARC_1 to _3 | Three heading arcs, the middle one in reverse, turn the car out of the lot to 35° without touching the parking-lot limitations. |
| PARKING_EXIT_FORWARD_ALIGN, PARKING_EXIT_REVERSE_VIEW | The car straightens to within 8° (at most 4.5 s), then reverses with the camera watching the start section, so the first pillar is seen before the car commits to a side. |
| PARKING_EXIT_SCAN | A pillar may stand just outside the parking lot. If it is on the side the car turns toward (red when driving clockwise, green anticlockwise), a timed pass keeps the car on its correct side; otherwise two heading arcs return the car to its lane. |
| ACQUIRE_PILLAR | One frame of red or green must not steer the car, so a pillar is followed only once 3 of 5 frames confirm it; an unconfirmed candidate is dropped after 1.2 s (`PILLAR_ACQUIRE_TIMEOUT_SECONDS`). |
| CONFIRM_PASSED | The camera loses a pillar before the rear of the car has cleared it, so the car holds its line for 0.25 s (`PILLAR_CLEARANCE_HOLD_SECONDS`). |
| PILLAR_RECENTER | A pass leaves the car angled towards a wall. A timed counter-steer alone would not prove the drift was cancelled, so the car counter-steers until its heading swings back past straight, then centres between the walls (§10). |
| APPROACH_CORNER | Neither a tape line nor a short front distance alone proves a corner. The approach locks after three fresh front readings of 105 cm or less; the turn needs the end wall within 35 cm (`OBSTACLE_CORNER_TRIGGER_CM`), the side the car turns toward open to at least 150 cm and the heading within 12° of the straight, in 3 agreeing samples over 0.25 s. After 3 s without a corner the car resumes the straight. |
| TURN_90 | The target is the straight's heading plus or minus 90°, reached within 5° (`TURN_HEADING_TOLERANCE`). With at least 60 cm of room on the outer side (`CORNER_REVERSE_CLEARANCE_CM`) the turn starts with a reverse arc of up to 0.5 s; if a wall blocks the reverse, the turn continues as a forward arc. |
| POST_TURN_BACKUP, POST_TURN_SCAN_HOLD | After each corner the car reverses for 0.35 s at speed 125 and stops for 0.2 s, "so several stationary frames can prove a nearby pillar" before the next straight. |
| CORNER_CLEARANCE_RECOVERY | A car pressed against the end wall cannot turn. It reverses (speed 150, at most 0.4 s per attempt, up to 3 attempts) until the front has 30 cm of clearance, then re-checks the corner while stopped. |

## 5. Edge cases the code handles

| Situation | What happens |
|---|---|
| Telemetry or camera stale, or a sensor invalid | Brake and hold the current state; resume when fresh. |
| A third pillar on one straight | Ignored until the corner (live view: CORNER NEXT - NO NEW PILLAR). |
| Only one pillar on a straight | 3.6 s after it, the second slot is filled and the corner takes priority (`SECOND_PILLAR_SLOT_TIMEOUT_SECONDS`). |
| Candidate pillar not confirmed | Back to FOLLOW_STRAIGHT after 1.2 s. |
| Pillar beyond the corner seen right after a pass | The corner is taken first (§2). |
| A side wall close during a pillar pass | A correction away from it from 18 cm, with fixed critical and emergency steers at 10 and 6 cm (§10). |
| Front at 5 cm | A short reverse, then a fresh check for a pillar, a corner or a clear front before moving on (§3). |
| Reverse blocked during a turn | The turn continues as a forward arc. |
| Both side walls too close for a corner reverse | FAULT (§3). |
| Twelfth corner | Hand-over to the parking module (§8). |

## 6. Known limits

- The driving direction is locked at the start and does not change during the run.
- The last-resort front trigger (`PYTHON_EMERGENCY_RELEASE_CM = 5`) is inside the TF-Luna's blind zone: its specified range starts at 0.2 m (vendor). Corners are normally handled from 105 cm, so this trigger only acts after a misjudgement.
- The ESP32 always reports `hardStop = 0` ([vehicle §7](apac_2026_vehicle.md)), so the `hard_stop` checks in `main.py` never fire.
- FAULT stops the car for the rest of the run.
- After the twelfth corner `main.py` hands over to the parking module its switches select; it stops with an error if both or neither are on (§8).
- Both parking modules end the entry when the front TF-Luna reads 5 cm or less (`ENTRY_STOP_FRONT_CM = 5`), and `partial_parking.py` also uses limits of 6, 8 and 15 cm (`REVERSE_BLOCK_SEARCH_SIDE_STOP_CM`, `REPOSITION_SIDE_CLEARANCE_CM`, `REPOSITION_FRONT_CLEARANCE_CM`). All are inside the TF-Luna's blind zone.
- In `parallel_parking.py`, FINAL_REVERSE, FINAL_BRAKE and FINAL_FORWARD are defined, but no transition leads into FINAL_REVERSE, so none of the three is reached; PARALLEL_ALIGN ends the parking in COMPLETE.
- The docstrings of `parallel_parking.py` say its detector does not use the blocks' colour; the code (`ParkingGeometryDetector.extract`) keeps only magenta pixels.

## 7. Validation

The metrics that exist, and how the next ones are collected.

- **Run results, 15–22 September** (the car's own logs, [APAC 2026 test logs](apac_2026_test_logs.md)): 27 runs from the parking lot reached the twelfth corner, 22 of them on 18–20 September in a median of 176 s (fastest 154 s); `parallel_parking.py` parked in 15 of 32 attempts on 20 September.
- **Detector, per frame.** The live view shows the tracked pillar's confidence, hits out of 5, bottom position and area band (§9); in the two captured frames of 2026-09-12 the track had 5 of 5 hits at confidence 0.92 and 0.86.
- **APAC bench, 2026-09-21.** Drive and power measurements in [vehicle §3 and §5](apac_2026_vehicle.md): free-running and stall currents, 422 rpm at the rear wheel, 0.89 m/s over 3 m from a standing start, the current of each supply branch.
- **Run logs.** `main.py` can log every run: with `ENABLE_RUN_CSV_LOGGING = True` (committed as `False`) it writes `run_logs/round2_run_<date_time>.csv` beside itself, one row per telemetry sample and one per event, with lap, corner count, pillars this straight, state, heading and target, the three distances, the command sent and applied, the tracked pillar with its band, and the tape depths. Those files give corners completed, pillars passed, recoveries and faults per run; the 260 runs logged from 15 to 23 September are summarised in [APAC 2026 test logs](apac_2026_test_logs.md). For parking, `parallel_parking.py` with `ENABLE_RUN_LOGGING = True` (committed as `False`) writes a CSV and an annotated video per attempt (§8).

## 8. Parking modules

Two files beside `main.py` park the car at the end of the run. After the twelfth corner `main.py` enters PARKING_PARALLEL_HANDOFF and calls the one its switches select (`PARTIAL_PARKING = True` and `PARALLEL_PARKING = False` as committed; exactly one must be on). Each can also run on its own, and each imports `main.py` for the camera, the serial link, telemetry, the live view and the shutdown. At the hand-over `main.py` first registers itself as the module `main` (`sys.modules`), so the parking module reuses the camera, serial port and telemetry already running ("give the standalone parking module the same initialized camera, serial port, telemetry, and safety API"). Constants named in this section are in the parking files.

| File | What it does | Start |
|---|---|---|
| [`parallel_parking.py`](../src/apac-2026/obstacle-challenge/parallel_parking.py) | Parallel parking (`BUILD_ID = "slot-guided-entry-v29"`): finds the two parking-lot limitations with the camera, drives into the gap between them and straightens up | `python parallel_parking.py --direction clockwise --last-pillar auto` |
| [`partial_parking.py`](../src/apac-2026/obstacle-challenge/partial_parking.py) | Direct entry: the same approach and block search, then a drive into the space on a locked heading ("Standalone 90 degree parking" in its help text) | `python partial_parking.py --direction clockwise --last-pillar auto` |

`--direction` is `clockwise` or `anticlockwise`; `--last-pillar` is `auto` (detect a red or green final pillar), `red`, `green` or `none`. Both wait for the start signal as `main.py` does, and end in COMPLETE with the brake held (exit code 0) or in FAULT with a printed reason (exit code 1).

**Which one.** A full parallel park scores 15 points against 7 for a partial or non-parallel one (2026 General Rules, scoring element 1.8.2), and touching a limitation ends the round (rule 9.24.7). As committed, the switches select `partial_parking.py`; parking parallel means setting `PARALLEL_PARKING = True` and `PARTIAL_PARKING = False`. Every `main.py` name the parking modules use exists in the committed `main.py`.

**Camera calibration.** Both files need `parking_camera_calibration.json` beside them. It depends on how the camera is mounted; the team's file, made with the September camera mount, is committed beside them. To make a new one: `python parallel_parking.py --calibrate` shows the camera image, and clicking the four corners of a rectangle on the floor (near-left, near-right, far-right, far-left; 100 × 150 cm unless `--calibration-width-cm` and `--calibration-depth-cm` say otherwise) saves the homography from image to floor. If the file is missing, `parallel_parking.py` starts this calibration itself and exits after saving.

### Finding the space (`parallel_parking.py`)

1. **Colour mask.** Pixels that are magenta in both HSV (`MAGENTA_HSV_LOW` 135, 65, 45 to `MAGENTA_HSV_HIGH` 179, 255, 255) and Lab (a ≥ 145, b ≤ 175). The top 28 % of the image is ignored (`ROI_TOP_FRACTION = 0.28`); one opening and two closings with a 5 × 5 kernel remove specks and fill gaps.
2. **Shape.** Each contour's rotated rectangle must fit a 200 × 20 × 100 mm limitation seen face-on, edge-on or at an angle: aspect 1.15 to 6, rectangularity at least 0.42, magenta fill at least 0.45, width at most 30 % and height 5.5 to 72 % of the image, lower edge below 55 % of the image height and not cut off by the bottom of the image.
3. **Floor position.** The midpoint of the rectangle's two lowest corners goes through the calibration homography, which gives the block's position on the floor in cm.
4. **Two blocks.** A block is confirmed after 3 hits in its last 6 frames (`BOUNDARY_REQUIRED_HITS`, `BOUNDARY_HISTORY`). Block 1 is the best-scoring rectangle on the parking side of the image. Block 2 must not overlap it, and must be 25 to 120 cm from it on the floor, within 55 cm of it sideways and at least 15 cm farther away.
5. **Slot.** The slot is the floor midpoint of the two blocks. It is confident when both blocks are confirmed, neither has been missed for more than 2 frames, they are 25 to 120 cm apart and both have a confidence of at least 0.55. Its bearing from the camera steers the car (`SLOT_BEARING_KP = 2.0`) and is used only within ±30° (`SLOT_MAX_USABLE_BEARING_DEG`).

### States (`parallel_parking.py`)

| State | What the car does | Leaves when |
|---|---|---|
| SEARCH_LAST_PILLAR | Looks for the final pillar with `main.py`'s pillar detector | a pillar is confirmed: PASS_LAST_PILLAR; no pillar and block 1 confirmed: TRACK_OPENING |
| PASS_LAST_PILLAR | Steers past the final pillar | red path: SEARCH_FIRST_BOUNDARY; green path: GREEN_RETURN_STRAIGHT back to the start heading, GREEN_FORWARD_STRAIGHT for 1.0 s, then SEARCH_FIRST_BOUNDARY |
| SEARCH_FIRST_BOUNDARY | Drives at speed 50 on the start heading turned 45° towards the parking side (5° after a green-path pillar). If block 1 is not confirmed within 4 s, a short reverse (0.6 s at speed 60, steer 45) and the search restarts; each retry adds 5° of offset (up to 55°), 0.2 s of search time and a longer, sharper reverse (up to 1.0 s, steer 55; the speed stays 60) | block 1 confirmed: TRACK_OPENING |
| TRACK_OPENING | The same search | block 2 confirmed and the slot confident: ALIGN_VIRTUAL_CUTOUT |
| ALIGN_VIRTUAL_CUTOUT | Speed 50, steering on the slot bearing (at most 25) | 8 consecutive updates with a usable bearing (`ALIGN_CONFIRM_SAMPLES`): ENTER_SPACE; front TF-Luna at 5 cm or less: PARALLEL_ALIGN |
| ENTER_SPACE | Speed 70, steering on the slot bearing (at most 12) | front TF-Luna at 5 cm or less: PARALLEL_ALIGN |
| PARALLEL_ALIGN | Speed 50 at full correction steer (50): reverse strokes of 0.8 s, then forward until the front TF-Luna reads 5 cm | heading within 2° of 0° on 3 consecutive updates: COMPLETE |

The red and green paths swap in an anticlockwise run (`pillar_behavior`). After a green-path pillar, each block search ends in FAULT after 15 s (`GREEN_PARKING_SEARCH_MAX_SECONDS`), and the return to the start heading after 10 s.

### What `partial_parking.py` changes

- **No final pillar.** With `--last-pillar none`, or when no final pillar is confirmed within 3 s, it drives straight for 2 s at speed 80 (NO_PILLAR_STRAIGHT), then searches for block 1 in reverse at speed 50 (REVERSE_BLOCK_SEARCH).
- **Green path.** Clockwise with a green final pillar (anticlockwise with a red one) it steers 45° forward until the centre TF-Luna reads 30 cm, then turns slowly at full lock the other way to a set heading before the block search (GREEN_CW_TURN_RIGHT, GREEN_CW_TURN_LEFT; mirrored as RED_ACW_TURN_LEFT, RED_ACW_TURN_RIGHT).
- **Opening check.** Where the parallel module would start aligning, it requires a visible opening at least 6.5 % of the image wide (`MIN_VISIBLE_ENTRY_GAP_RATIO`) and a slot at least 20 cm ahead with a valid bearing. A narrower opening gets one repositioning (REPOSITION_AWAY, REPOSITION_FORWARD, REPOSITION_RETURN) before a FAULT.
- **Entry.** It locks the entry heading at the current heading plus the slot bearing (at most ±30°) and drives in at speed 70, the parallel module's `ENTRY_SPEED` (ENTER_SPACE). Steering is 2.0 × the heading error plus 0.6 × its integral, which builds only once the slot is closer than 40 cm, plus a smoothed term of at most 8 that centres the opening in the image while the slot is 40 cm or more away; at most 24 in total.
- **Stop.** At a front reading of 5 cm or less, or when the front reading is missing or stale, it brakes (FRONT_SENSOR_HOLD): 3 fresh readings at the stop move on to PARALLEL_ALIGN, and 3 fresh clear readings resume the previous state. PARALLEL_ALIGN works as in the parallel module but counts only fresh telemetry.

### Why it is built this way

Reasons as the code's comments give them.

| Choice | Reason given in the code |
|---|---|
| The TF-Luna sensors are not used while searching for or aligning with the blocks | The blocks' geometry comes from the full camera view; distance matters only once the car is in the space |
| A short camera miss does not brake the car | The brake is not pulsed between camera frames: the selected motion continues until vision recovers, and during alignment the car drives straight and restarts the confirmation |
| Avoiding the final pillar starts on its first sighting, but the pass needs several frames of confirmation | At driving speed a one-frame delay can put the pillar past the useful steering window; a false detection can steer briefly but cannot latch the pass |
| The block search holds a heading offset towards the parking side | So that the blocks enter the camera view; an earlier path turned into the parking area before block 1 was confirmed |
| Reverse strokes in PARALLEL_ALIGN stop after 0.8 s; forward moves stop on the front TF-Luna | So that the car cannot back out of the space |
| The shape limits are broad | A limitation can be seen edge-on, face-on, at an angle or cut off by the image edge |
| One magenta contour never updates both blocks, and a sudden inward jump is taken as the next block | Block 1 leaves the image through its left edge in a clockwise run (the right edge anticlockwise), so a new rectangle further in is block 2, never a new sample of block 1 |
| `partial_parking.py` ignores a pillar cut off by the image edge | Such an object belongs to the next lane, not to the final pillar ahead |

### Failure exits

Every FAULT prints its reason and holds the brake.

- `parallel_parking.py`: after a green-path pillar, the return to the start heading takes more than 10 s, or block 1 or block 2 is not found within 15 s.
- `partial_parking.py`: no valid IMU heading when the entry heading is locked; the opening is still narrower than 6.5 % of the image after one repositioning; the slot is not ahead with a valid bearing; something in front while the final pillar is classified, during the no-pillar straight or during the pillar pass; the pillar pass takes more than 4 s; too little side clearance in the reverse search; too little front or side clearance while repositioning; the opening is lost before the car passes it.

## 9. Pillar and line detection

What `UnifiedPillarDetector` does with each 1280 × 720 frame, and why. Constants are in `main.py`; the two figures at the end show the result on the mat.

1. **Image preparation.** The frame is stretched (`CONTRAST = 3.0`, `BRIGHTNESS = 0`) and gamma-corrected (`GAMMA = 0.7`), then converted to Lab; CLAHE (clip 2.0, 8 × 8 tiles) evens out the lightness channel. Lab keeps lightness apart from the two colour axes, so red (high a) and green (low a) separate with L left open, and a brighter or darker hall mostly moves L ([vehicle §4](apac_2026_vehicle.md)). The venue's thresholds come from one practice round with `lab-calibration.py`.
2. **Side masks.** Before detection a strip at each side of the frame is set to neutral grey (128, outside every Lab range) without moving pixel coordinates (`asymmetric_camera_view`): 16 % of the width on each side on a straight (`CAMERA_SIDE_MASK_FRACTION`). After a corner the two sides are masked separately, depending on the turn direction (`post_turn_view_fractions`, `POST_CORNER_VIEW_SIDE_FRACTION = 0.20`), until the new straight is established: 1.5 s of forward driving, or 12 s.
3. **Colour masks.** One Lab range per colour (`COLOR_RANGES`, as committed): red a at least 184 and b at least 108; green a at most 101; blue a 153 to 186 and b at most 90; orange a at least 130 and b at least 150; L unconstrained. Each mask is opened once and closed twice with a 3 × 3 kernel, and the top third of the image is cleared (`DETECTOR_ROI_TOP_RATIO`): from the 24.8 cm mount that third lies above the tops of the walls out to about 3 m ([vehicle §4](apac_2026_vehicle.md)), so it holds only the hall.
4. **Candidate shapes.** Each contour is tested by size and shape. Pillars (red, green): area at least 0.045 % of the frame and height at least 2.5 % of the frame height; height to width 0.65 to 8 (a 50 × 50 × 100 mm sign is about twice as tall as wide; the range allows partial views and perspective); rectangularity at least 0.35 and solidity at least 0.60, since a pillar is a solid rectangle and tape edges and reflections are not. Tape lines (blue, orange): area at least 0.03 %, height at least 1 %, height to width 0.2 to 10, rectangularity at least 0.25, solidity at least 0.50. Confidence = 0.20 × area + 0.20 × height + 0.25 × rectangularity + 0.35 × solidity, with area and height capped at 5 × the minimum area and 25 % of the frame height; candidates under 0.45 are dropped (`DETECTOR_MIN_CONFIDENCE`).
5. **Tape lines and the corner reference.** The mat's blue and orange lines mark the approach to a corner. They are found in HSV (blue hue 95-135, orange hue 3-22) below the top third, with the same morphology; a line must cover 0.025 % of the frame, span 10 % of its width and be at least twice as wide as tall. The lowest line's mid-height is its depth; when both colours are visible, the deeper of the two is the corner reference (the magenta line in the live view). The code also confirms a corner from the black walls: in HSV (value at most 70), a broad black end wall with an opening on the turn side, confirmed in 3 of the last 4 frames (`BLACK_CORNER_*`).
6. **Which pillar counts.** With the corner reference visible (and not suppressed for 3 s after a turn, `POST_TURN_TAPE_IGNORE_GRACE_SECONDS`), a pillar whose centre is above the reference, farther away than the tape, is ignored when it is entirely above it or sits in an outer column of the 5 × 5 grid: it stands beyond the corner or in a side lane (IGNORE CORNER in the live view). Two rules keep the car from dropping the obstacle in front of it: the track the controller is already passing keeps priority even when tape moves in front of it (FRONT PRIORITY), and when a larger, lower interior pillar and a smaller outer pillar are both beyond the reference, the interior pillar stays actionable if it is 1.25 × larger (`CORNER_FOREGROUND_AREA_ADVANTAGE`). A small ignored pillar never suppresses a valid foreground pillar.
7. **Tracking.** One pillar is tracked at a time. A new track starts on the best candidate by 0.55 × bottom + 0.35 × confidence + 0.10 × area: the lowest in the image is the nearest. Each frame the track is matched to a same-colour candidate by centre distance (at most 0.25 of the frame) or overlap (IoU at least 0.05), and its position is smoothed (0.65 new, 0.35 old). A track is confirmed after 3 hits in its last 5 frames (`DETECTOR_CONFIRMATION_HITS`, `DETECTOR_TRACK_HISTORY`); an unconfirmed track is dropped after 2 misses (`DETECTOR_UNCONFIRMED_MISSES`); a confirmed track stays locked until the controller records the pass, so a brief occlusion cannot switch the target. Confidence is 0.75 × the detection's confidence + 0.25 × hits/5, and decays by 10 % per missed frame.
8. **Two pillars per straight**. At most two pillars are taken on each straight (`MAX_PILLARS_PER_STRAIGHT = 2`); once both are passed, no new pillar is taken until the corner (live view: CORNER NEXT - NO NEW PILLAR). If no second pillar has come 3.6 s after the first, slot 2 is filled and the corner takes priority (`SECOND_PILLAR_SLOT_TIMEOUT_SECONDS`). One high track in the next lane is deferred rather than its whole colour suppressed, and right after a turn nearby pillars take priority (`defer_background_candidate`). A wide, low rectangle, at least twice as wide as tall, is treated as a parking-lot limitation, not a pillar; in laps 1 and 2 the car steers gently around it (speed 60, steering 15).
9. **Range and control.** The pillar's distance band comes from its area: far under 3,200 px×px, near under 7,000, close under 20,000, otherwise too close; the 1280 × 720 breakpoints are kept as ratios of the frame (`PILLAR_AREA_NEAR_RATIO`, `PILLAR_AREA_CLOSE_RATIO`, `PILLAR_AREA_TOO_CLOSE_RATIO`). Each band selects a speed, gain and steering limit (`PILLAR_DISTANCE_PROFILES`; far: speed 100, gain 0.70, 3 to 12 of steer; too close: speed 80, gain 1.50, 38 to 52). The controller steers the pillar to a target column, red to 38 % of the width so the car passes on its right and green to 62 % so it passes on its left (`PILLAR_RED_TARGET_X`, `PILLAR_GREEN_TARGET_X`), with gain 200 (`PILLAR_LATERAL_KP`), at most 40 of correction and smoothing 0.65.

**The live view** (`annotate`): the cyan line is the top of the search area; the grey grid is the 5 × 5 columns and rows; blue and orange boxes are tape lines; the magenta line is the corner reference; thin boxes are candidates; a magenta box is a pillar ignored as beyond the corner (`IGNORE CORNER Cn`, n = grid column); a yellow box marks the pillar being passed (`FRONT PRIORITY`); the tracked pillar's box is yellow once confirmed and cyan before, labelled `TRACK id COLOUR conf hits/5 bottom area BAND`, with a vertical line at its target column; the text lines give the state, heading and steer, and the three TF-Luna readings in cm. The live view also shows PILLAR SLOTS n/2, CORNER NEXT - NO NEW PILLAR, SLOT 2 TIMEOUT IN n s, BLACK CORNER and VIEW MASK L=n% R=n%.

Two frames from testing on 12 September.

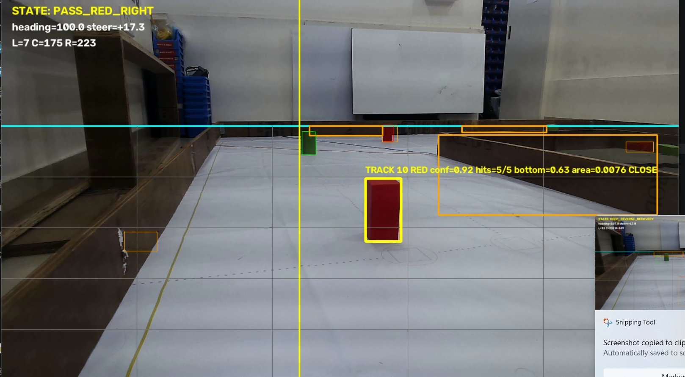
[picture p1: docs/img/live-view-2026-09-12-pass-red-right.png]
Passing a red pillar: state PASS_RED_RIGHT, track 18 at confidence 0.92


Passing a red pillar: state PASS_RED_RIGHT, steer +17.3 at heading 100.0; TF-Luna L 7, C 175, R 223 cm; track 18, red, confidence 0.92, 5 of 5 hits, bottom 0.63, area 0.0076, band close; orange tape boxes ahead and the red target column drawn.

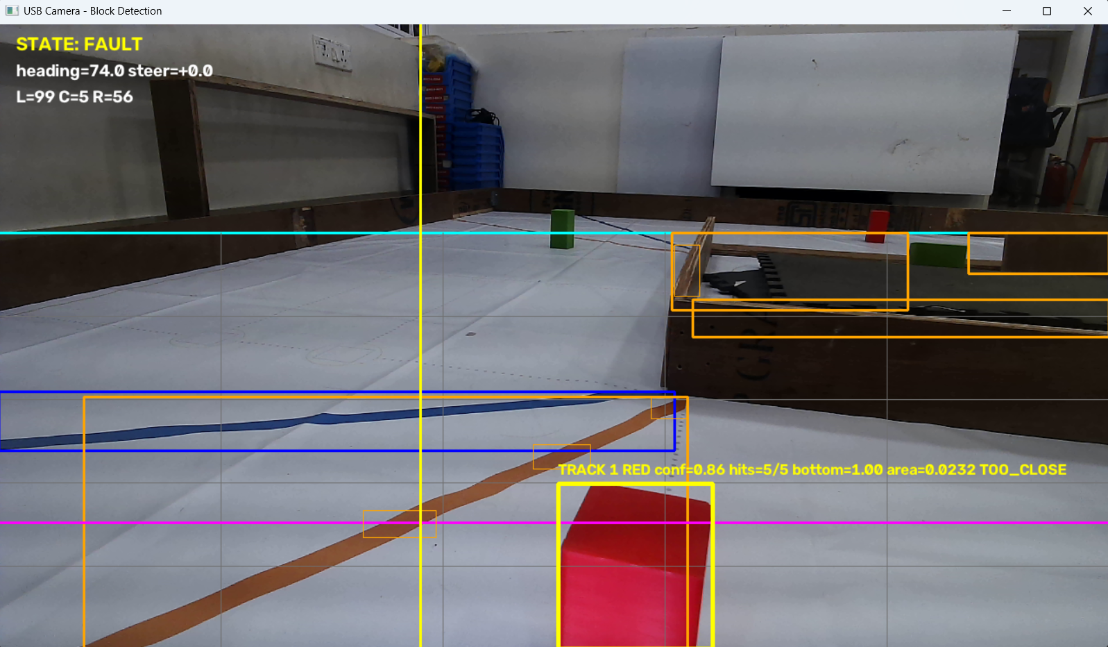
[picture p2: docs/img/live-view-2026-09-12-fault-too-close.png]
A run ended in FAULT with a red pillar 5 cm from the centre TF-Luna


A run that ended in FAULT: a red pillar 5 cm from the centre TF-Luna (L 99, C 5, R 56 cm), track 1 at confidence 0.86, bottom 1.00, area 0.0232, band too close; both tape lines are visible and the magenta corner reference is drawn. The fault reason is printed to the terminal, not to the view, and was not captured.

## 10. Staying off the walls

Four mechanisms keep the car in the middle of its lane; with them the side rollers were no longer needed ([vehicle §7](apac_2026_vehicle.md)).

- **PILLAR_RECENTER**, after every pillar pass, counter-steers 22° against the pass for 0.18 to 0.45 s and moves on once the heading has swung back past straight, "proof it actually cancelled the drift, not just a timer"; it then settles onto the lane centre from the heading and both side TF-Lunas (both walls 8 to 110 cm away, heading within 10°, gain 0.5, at most 18 of steer, 3 confirmations).
- **A wall guard during pillar passes**: a side wall closer than 18 cm (`PILLAR_WALL_WARNING_CM`) adds a correction away from it that grows to 35 at 6 cm; at 10 cm a fixed critical steer takes over, and at 6 cm an emergency steer at speed 65.
- **Recentering after corners**: a side-distance correction (`ROUND2_RECENTER_*`: gain 0.45, at most 14, heading within 8°).
- **CORNER_CLEARANCE_RECOVERY** (§4), with the side-clearance check before a corner reverse (`TURN_SIDE_CLEARANCE_CM = 20`).

## 11. Open Challenge firmware

[`open-challenge/open-challenge.ino`](../src/apac-2026/open-challenge/open-challenge.ino) drives the Open Challenge on the ESP32 alone, without the Raspberry Pi or the camera. It uses the same pins, I2C multiplexer channels and sensors as the Obstacle firmware; the servo centre is `SERVO_CENTER = 106` here and 85 in the Obstacle firmware. Constants are in the file.

1. **Start and direction.** After the start button (GPIO32), the car drives at speed 190 (`DETECTION_SPEED`) until one side reading opens beyond 100 cm on 3 samples (`DIRECTION_DETECTION_DISTANCE_CM`, `DIRECTION_CONFIRMATION_SAMPLES`); that side sets clockwise or anticlockwise, keeping the original priority for the right side.
2. **Wall following.** At speed 190 (`FOLLOW_SPEED`) the car holds its heading (gains 0.55 and 0.08, `HEADING_KP`, `HEADING_KD`) and keeps 30 cm from the followed wall (`TARGET_LEFT_DISTANCE_CM`, `TARGET_RIGHT_DISTANCE_CM`; gain 0.50, at most 12), with at most 25 of steering in total.
3. **Corners.** When the followed side opens beyond 75 cm on the left or 50 cm on the right on 3 samples, the car turns 90° on the BNO055 heading at speed 160 (gains 0.75 and 0.06, at most 35 of steering) until the error is under 4°. It then drives at speed 210 for a minimum time (500 ms clockwise, none anticlockwise) and reacquires the wall below 50 cm on 3 samples.
4. **Finish.** After twelve turns (`TOTAL_TURNS`) it holds the heading of the last turn and brakes when the centre TF-Luna reads 150 cm or less (`FINAL_CENTER_DISTANCE_CM`); the electrical brake then stays latched.

The control loop runs every 10 ms (`CONTROL_PERIOD_US`), and servo pulses come from a dedicated task on the other core (`servoPulseTask`, 20 ms frames).

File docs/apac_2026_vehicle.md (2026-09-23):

# APAC 2026 vehicle — changes since Nationals

**Scope.** The vehicle that competes at WRO Future Engineers APAC 2026, built after the India National Championship (26–28 Aug 2026): what changed and why. Every figure is marked by its basis: *measured* on the vehicle, *team* figure not yet measured, *derived* by calculation from named inputs, or *vendor* specification. Documents 1–5 remain the record of the Nationals configuration.

## 1. Specification

| | Nationals (Aug 2026) | APAC 2026 (Sep 2026) | Basis |
|---|---|---|---|
| Length × width × height | length 23.0 cm | 19.1 × 14.3 × 27.2 cm (±0.5 cm) | measured |
| Mass | 785 g | 862 g race-ready, Raspberry Pi 5 included (measured 2026-09-16) | measured |
| Axle loads | — | front 201 g, rear 661 g (23 % / 77 %) — see §2 | measured |
| Chassis | LEGO Technic space-frame, 69-step build | LEGO Technic frame, 84-step build ([instructions](../models/chassis/chassis_build_instructions_apac_2026-09.pdf)); 332 g bare | build file; measured |
| Printed parts | TF-Luna holders, servo horn beam, motor clamp ([`models/`](../models/)) | the same STL files | team |
| Steering | single-servo Ackermann (MG90S) | non-Ackermann: an MG90 servo drives a vertical steering column that turns the front axle, 60° each side | team |
| Wheelbase | — | 13 cm | team |
| Wheels | front 41 mm, rear 55.6 mm | front 45 mm, rear 55 mm (rear tyres chosen for grip) | team |
| Drive motor | N20 gearmotor, 12 V, 600 rpm, via TB6612FNG | MEX motor (Avishkaar), rated 6 V, 400 rpm, via TB6612FNG — see §3 | team |
| Gearing | 20T pinion → 28T crown on a LEGO differential (5:7) | unchanged | team |
| Battery | 3S LiPo, 11.1 V, 2200 mAh | unchanged | team |
| Power | pack → fast-charge module → Pi 5; pack → Buck-2 → 5 V rail (TF-Lunas, servo); TB6612FNG from the pack ([2 — Power & Sensors](2_power_and_sensors.md)) | unchanged, plus the WS2812 LEDs on the 5 V rail; power switch on the battery lead; start button on the rear beams | team |
| Sensors | 3 × TF-Luna on a PCA9548A, BNO055, USB camera on a front arm at ~10 cm | same sensors; the camera (Lenovo 300 FHD) sits on top of a rear tower — see §4 | photos; measured |
| Lighting | none | 6 × WS2812 LEDs (three 2-LED strips) on the front frame — see §5 | team |

Wiring: [`schemes/wiring_apac_2026.md`](../schemes/wiring_apac_2026.md). Photos: [`v-photos/apac-2026-09-22/`](../v-photos/apac-2026-09-22/) — six views, 2026-09-22.

## 2. Weight and balance

| Quantity | Value | Basis |
|---|---|---|
| Total, race-ready | 862 g | measured |
| Front / rear axle | 201 g / 661 g (23 % / 77 %); the two sum to the total | measured |
| Centre of mass | 10.0 cm behind the front axle (13 cm × 661 / 862) | derived |
| Bare chassis | 332 g, split 31 % / 69 % | measured |
| Everything added to the chassis | 530 g, about 82 % on the rear axle | derived |

Assuming the added parts share the chassis's split would have put 67 g too much on the front, which is why the full car was weighed per axle.

The driven rear wheels carry 77 % of the weight, which helps traction. The steered front wheels carry 23 %, on the smaller tyres, so front grip is what limits cornering. Planned check: measure the turning circle at walking pace and at race speed; a much wider circle at speed means the front is sliding.

## 3. Drive

- **Motor:** MEX motor (Avishkaar), rated 6 V and 400 rpm no-load (team).
- **Speed at the rated voltage:** 400 rpm × 20/28 = 286 rpm at the rear wheels; × π × 55 mm = **0.82 m/s no-load** (derived).
- **Voltage the motor sees:** the TB6612FNG switches the pack (11.1 V nominal, 12.6 V full) with PWM, so the motor's average voltage is duty × pack voltage. With the Nationals firmware, full commanded speed was 100 % duty (12.47 V measured at the motor terminals) and half speed was 48 % duty (5.95 V) — see [2a](2_power_predicted_budget.md). On a 6 V motor, duty above about 48 % on a full pack averages more than its rating. The APAC firmware writes the duty directly with an 8-bit `analogWrite` and no cap: `SPEED = 210` is 82 % duty, 9.1 V average on the nominal pack and 10.4 V on a full one, 1.5–1.7 times the motor's 6 V rating (derived). Turning (`100`, 39 %), parking (`70`, 27 %) and the collision escape (`80`, 31 %) stay under the rating. The motor temperature after a full 3-minute run has not been measured yet.
- **Measured 2026-09-21** (pack at 12.3 V, `SPEED = 210`, so 10.1 V average; ammeter in the motor wire unless stated):

| Test | Result | Basis |
|---|---|---|
| Rear wheels lifted, free-running | 0.33 A; rear wheel 422 rpm (slow-motion video of a taped wheel, counted over one minute) = **1.22 m/s** | measured |
| Driving on the mat | 0.599 A | measured |
| Wheels held (stall), ammeter on the battery lead | 1.24 A, which is 1.51 A through the motor at 82 % duty | measured; motor figure derived |
| 3 m straight line from a standing start | 3.36 s, 0.89 m/s on average with the launch included | measured |

- **Speed check.** Scaling the rated 400 rpm linearly to 10.1 V predicts 482 rpm at the rear wheel. The measured 422 rpm is 12.5 % lower, because linear scaling ignores the voltage lost in the winding and the drivetrain friction that shows up as the 0.33 A free-running current.
- **Motor model** (derived). Treating the motor as a standard DC motor (voltage = current × resistance + speed × motor constant) and fitting it to the free-running and stall points gives 6.71 Ω including the driver and 0.128 V·s/rad at the gearmotor output. At the measured 0.599 A on the mat it predicts 0.94 m/s, and 3.37 s for the 3 m standing start (launch time constant 0.17 s). The measured time is 3.36 s.
- **Torque and grip** (derived; drivetrain efficiency beyond the free-running losses assumed 0.8). The rear axle gets about 0.04 N·m while cruising (1.4 N at the tyres, the rolling and drivetrain load on the mat) and 0.17 N·m at stall (6.2 N at the tyres). The rear tyres carry 6.5 N (661 g), so 6.2 N would need a friction coefficient of 0.95: a hard launch or a push against a wall spins the rear wheels on most surfaces before the motor stalls.

## 4. Camera placement

- **Mount:** lens centre 24.8 ± 0.5 cm above the floor; optical axis 12° below horizontal (78° from straight down); the hinge is glued at that angle (measured).
- **Field of view:** Lenovo lists a 95° diagonal field of view ([product page](https://store.lenovo.com/in/en/lenovo-300-fhd-webcam-gxc1b34793-387.html)), which is about 56° vertical and 87° horizontal at 16:9 (derived; not measured on this camera).

| Quantity | Formula | Value |
|---|---|---|
| Where the optical axis meets the floor | h / tan α | 117 cm ahead of the lens; about ±10 cm per 1° of angle error |
| Nearest floor in view | h / tan(α + VFOV/2) | ~29 cm from the lens; the lens sits ~10 cm behind the front wheels, so ~19 cm ahead of them |
| Separation of pillar bases at 0.5 m and 1.0 m | atan(h / 0.5 m) − atan(h / 1.0 m) | 12.5° (5.6° with the Nationals 10 cm mount) |
| Tops of walls 1–3 m away | α − atan((h − 10 cm) / D) | 3.6°–9.2° above the image centre |

h = lens height, α = pitch below horizontal, VFOV = vertical field of view, D = distance to the wall.

**Why the camera went up.** Reading range from the image depends on how low a pillar's base sits (the Nationals rule, [2 — Power & Sensors §3](2_power_and_sensors.md)). Raising the lens from ~10 cm to 24.8 cm makes that signal about 2.2 times stronger (12.5° against 5.6° between pillars at 0.5 m and 1.0 m), and the centre of the image lands ~1.2 m ahead instead of 0.33–0.57 m. The separation keeps growing with height up to h = √(Z_near · Z_far), 55 cm for pillars at 0.3 m and 1.0 m, so the earlier statement in §3 of that document, that a higher mount compresses it, was wrong; it is corrected there.

**What it costs.**

1. A blind zone: a pillar within ~19 cm of the front wheels has its base below the frame, so the nearest-pillar rule needs a tie-break for boxes cut off at the bottom edge.
2. A view over the 100 mm walls: off-field objects can appear between the wall tops and the horizon, so the pillar search has to stay below the black wall band, not a fixed image row.

Planned checks: a tape on the floor slid until it just enters the bottom of the image (measures the blind zone directly); a start-position reference frame compared before each round (the hinge is glued, but this catches knocks).

### Colour calibration

The colour thresholds are set on the competition mat during one practice round at each venue, under that venue's lighting (team). Two tools in [`src/apac-2026/tools/`](../src/apac-2026/tools/) apply the same image processing as `main.py`: a contrast and brightness scale, a gamma curve, then contrast-limited histogram equalisation (CLAHE, clip limit 2.0, 8 × 8 tiles) on the lightness channel.

1. **Image.** `camera-settings.py` shows the live camera image with brightness, contrast and gamma sliders. The values chosen go into `BRIGHTNESS`, `CONTRAST` and `GAMMA` in `main.py` (committed: 0, 3.0 and 0.7).
2. **Colours.** `lab-calibration.py` converts the processed image to Lab and shows a mask while the lower and upper L, a and b sliders move. For each colour the sliders are set until only that colour shows in the mask, and the six values go into `COLOR_RANGES` in `main.py`.

Lab keeps lightness (L) apart from the two colour axes, so red (high a) and green (low a) can be separated with L left fully open, and a brighter or dimmer hall mostly changes L. The committed ranges do this: red is a ≥ 184 and b ≥ 108, green is a ≤ 101, both with L from 0 to 255. The blue and orange tape lines are found with fixed HSV ranges (`COURSE_LINE_HSV_RANGES` in `main.py`), not with these tools.

## 5. Lighting and power additions

- **LEDs:** 6 × WS2812 on the front frame; data from ESP32 GPIO4; power from the 5 V Buck-2 rail (team). The firmware lights them white at `setBrightness(80)`, about 31 % (the bench measurements were taken at 50, about 20 %): roughly 19 mA per LED and 0.11 A for all six by the 60 mA-per-LED full-white rule of thumb in the [Adafruit NeoPixel Überguide](https://learn.adafruit.com/adafruit-neopixel-uberguide) (derived). Full white would be 0.36 A.
- **Switch and button:** one power switch on the battery lead; the start button on the rear beams (team). The rules require exactly one power switch and one start button ([2 — Power & Sensors §6](2_power_and_sensors.md)).

### Power budget, measured 2026-09-21

Each branch was measured on its own lead from the pack (ammeter and voltmeter, pack at 12.3 V). Pack currents for the two 5 V converters are given at the nominal 11.1 V, the conservative case used in [2a](2_power_predicted_budget.md), with the converters assumed 88 % efficient; the motor branch is as measured.

| Branch | Feeds | Basis | Idle | Driving | Worst case |
|---|---|---|---|---|---|
| Buck-2 (5 V) | 3 TF-Luna, servo, 6 LEDs | measured at its input | 0.13 A | 0.23–0.32 A (servo sweeping) | 0.32 A |
| Fast-charge module (5 V) | Pi 5, camera, ESP32 | measured peak, 11.8 W at the Pi | 1.21 A | 1.21 A | 1.21 A |
| TB6612FNG | drive motor | measured | 0 | 0.49 A (0.599 A × 82 % duty) | 1.24 A (stall) |
| **Pack total** | | | **1.34 A** | **1.93–2.02 A** | **2.77 A** |

With the Pi's peak treated as its average, a 2200 mAh pack used to 80 % gives about 52 minutes of driving, about 17 three-minute runs (derived). The prediction for the Nationals car in [2a](2_power_predicted_budget.md) was 0.95–1.40 A driving; the difference is the Pi (an 11.8 W peak against 6.2–8.5 W predicted as an average) and the larger motor.

| Part | Load | Rating (vendor) | Use |
|---|---|---|---|
| TB6612FNG, one channel | 1.51 A through the bridge at stall; 0.60 A driving | 1.2 A continuous, 3.2 A peak | **126 % at stall**; 50 % driving |
| Pi 5 USB ports without USB-PD | camera + ESP32 | 600 mA in total | see §6 |
| Battery, 3S 2200 mAh 60C | 2.77 A worst case | 132 A | 2 % |

## 6. New failure points

| Risk | Effect | Check or mitigation |
|---|---|---|
| Pi 5 fed from a USB-A fast-charge module (no USB-PD) | The Pi peaked at 11.8 W (2.36 A at 5 V, measured) and the module's rating has not been read; without USB-PD the Pi limits its USB ports to 600 mA in total, and the camera and the ESP32 both draw from them | Run `vcgencmd get_throttled` after a full run; move to a 5 A USB-C PD supply if it reports problems |
| WS2812 data at the ESP32's 3.3 V | The LED input-high threshold is 0.7 × VDD (3.5 V at 5 V); a marginal signal can flicker or show the wrong colour, tinting the scene | Watch for flicker in the camera image; add a level shifter if seen |
| 6 V motor on the 11.1 V pack | Heat and brush wear: `SPEED = 215` averages 9.4–10.6 V, above the 6 V rating (§3) | Temperature check after a 3-minute run |
| Drive motor held against a wall | 1.51 A through the TB6612FNG at stall, above its 1.2 A continuous rating (§5); the driver's thermal shutdown or the motor's heating would stop the car | The Pi's distance logic backs away (escape at 31 % duty for 0.30 s, at least 3 cm of progress, at most 2 attempts); on most surfaces the rear wheels spin before a full stall (§3) |
| Firmware front stop: the ESP32 stopped the drive motor when the front TF-Luna read under 18 cm or its reading went stale | **Observed:** it stopped the car and ended a run (team) | Removed from the firmware on 2026-09-10; collision handling moved to the Pi (§7) |
| Camera angle | Pixel-based settings shift if the angle moves | Hinge glued; reference frame before each round |
| Background above the walls | Off-field red or green objects read as pillars | Search only below the wall band |
| Blind zone ahead of the wheels | The nearest-pillar rule ties for boxes cut off at the bottom | Tie-break rule in the code |

## 7. Why each change was made

Each change as a decision: what it replaced, the reason the team gives, the evidence in this repository, and what it costs. The largest test-driven change in this vehicle's line is in the Nationals record: the wheel-shed failure of 2026-08-06 led to the space-frame redesign that every later frame descends from ([1 - Mobility §3](1_mobility.md), [D8](4_systems_and_decisions.md)).

| Change | Instead of | Reason (team) | Evidence here | Trade-off |
|---|---|---|---|---|
| New 84-step frame, 332 g bare | the Nationals 69-step space-frame | a sturdier structure | build file; the car weighs 862 g against 785 g at Nationals (measured, all changes together) | 77 g more to accelerate and stop; stiffness not measured |
| Steering column turning the whole front axle, 60° each way | single-servo Ackermann | a smaller turning circle | turning circle not measured | the front wheels no longer follow Ackermann geometry, so they scrub in tight turns |
| Wheels: front 45 mm, rear 55 mm tyres | front 41 mm, rear 55.6 mm | rear tyres for grip | not measured | none recorded |
| Camera on a 24.8 cm tower, 12° down | a front arm at about 10 cm | a better view of the track | measured mount, derived geometry: pillar bases at 0.5 m and 1.0 m are 12.5° apart against 5.6° before, a 2.2 × stronger range signal (§4) | a 19 cm blind zone ahead of the wheels and a view over the walls (§4); a taller top, its centre-of-gravity height not measured |
| Six WS2812 LEDs on the front frame | ambient light | fewer colour mistakes | 0.11 A at the committed brightness of 80 by the rule of thumb (0.07 A at 50, the bench setting); Buck-2 idle 0.13 A measured with them (§5); misread counts not measured | data at 3.3 V may flicker (§6) |
| Side rollers fitted, then removed | none | fitted to keep the car moving on wall contact; removed once the rewritten wall-avoidance code made them unnecessary, and because they blocked the Raspberry Pi's ports (reported 2026-09-22) | the team ran the car in both configurations without trouble (team); in the logs of 22 September evening, after the removal, 5 of 7 short test runs reached COMPLETE, and the corner-clearance recovery ran in 5 of them ([test logs](apac_2026_test_logs.md) §4); the current `main.py` adds lane recentering after every pillar pass and after corners, a wall guard during pillar passes and a corner-clearance recovery ([software §10](apac_2026_software.md)) | without rollers a wall contact stops the car; only the Pi's collision escape (§6) remains |
| Firmware front stop removed (2026-09-10) | a stop under 18 cm on the front TF-Luna | stopping the drive motor ended a competition run | one run ended (team) | collisions are handled by the Pi's distance logic alone (§6) |
| Parallel parking at the end (`parallel_parking.py`) | direct entry (`partial_parking.py`) | 15 points for a full parallel park against 7 (2026 rules, scoring element 1.8.2) | rules; logs: 15 of 32 `parallel_parking.py` attempts parked on 20 September, while the U-turn parking-in of 17 September reached COMPLETE in 0 of 24 ([test logs](apac_2026_test_logs.md) §3) | a longer manoeuvre beside the limitations; touching one ends the round (rule 9.24.7) |

**The front-stop decision.** The firmware used to stop the drive motor when the front TF-Luna read under 18 cm (released at 24 cm) or when its reading went stale, and that stop ended a run. On 2026-09-10 `forwardHardStopIsActive()` was changed to return `false`, with the comment "Disabled: stopping the drive motor here ends a competition run". Collisions are handled on the Pi: back away at speed 80 for 0.30 s, require at least 3 cm of progress, at most 2 attempts, release at 30 cm. The same day added a `PARKING_OVERRIDE_ON` serial command to the firmware; `main.py` never sends it, so it has no effect in a run.
## 8. ESP32 pin map

From the Nationals firmware ([`round2_ino.ino`](../src/Round%202/round2_ino/round2_ino.ino)) and the 2026-09-20 wiring draft; only GPIO4 is new. Checked against the APAC firmware ([`src/apac-2026/`](../src/apac-2026/)) on 2026-09-21: it reads the centre TF-Luna on mux channel 3 (channel 1 at Nationals).

| Signal | GPIO |
|---|---|
| I²C SDA / SCL — PCA9548A at `0x70`: ch0 left, ch3 centre, ch2 right TF-Luna (`0x10`), ch4 BNO055 (`0x28`) | 21 / 22 |
| Steering servo | 13 |
| TB6612FNG AIN1 / AIN2 / PWMA / STBY | 25 / 26 / 33 / 27 |
| WS2812 data | 4 |
| Start button | 32 |

## 9. Still to add

- The wall-avoidance runs behind the side-roller removal (§7): how many, on which code version, with what result.
- Open Challenge and Obstacle Challenge videos of this vehicle.
- Measurements: turning circle at walking pace and race speed, the blind-zone tape check, motor temperature after a full run, `vcgencmd get_throttled` after a full run.
- LED misread counts on the same pillars with the LEDs off and on (§7).
- Run logs from `main.py` (with `ENABLE_RUN_CSV_LOGGING = True` it writes `run_logs/round2_run_*.csv`).

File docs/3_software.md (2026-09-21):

# 3 — Software Architecture & Obstacle Strategy

> **Scope:** this document describes the software flashed at Nationals (August 2026). The APAC 2026 code is in [`src/apac-2026/`](../src/apac-2026/) and its state machine in [`apac_2026_software.md`](apac_2026_software.md); the vehicle changes are in [`apac_2026_vehicle.md`](apac_2026_vehicle.md).

> **Status (2026-08-24).** The Round 2 configuration flashed at Nationals is
> [`src/Round 2/competition/`](../src/Round%202/competition/) — PID heading hold with a
> staged PAUSE→PASS→SIDE→YAW-BACK pass on the ESP32 (`test.cpp`), and a 2-class
> green/red ONNX detector with a 5-of-7 vote and 7-column offset LUT on the Pi
> (`detecttor.py`); see that folder's README and the Engineering Journal §08.
> The pipeline described below is the documented evolution that produced it and
> is retained as engineering history.

Two processors, one rule: **motion must never wait on perception.**

| Processor | Runs | Rate | Fails how |
|---|---|---|---|
| ESP32 | heading hold, corner detection, servo steering | ~50 Hz nominal (unmeasured) | If it stops, the vehicle stops |
| Raspberry Pi 5 | pillar detection, pass-side decision | vision-rate, unmeasured on Pi | If it stops, the vehicle keeps driving on its last heading target |

The split is deliberate. A detector stall on the Pi degrades the run to an Open
Challenge lap rather than ending it. Nothing in the steering loop blocks on a
vision result; the pass-side decision is an input the loop reads when present and
ignores when absent.

---

## 1. Open Challenge — implemented

`src/Round 1/round 1/round 1.ino`

1. On startup the current BNO055 Euler yaw is captured as the **target heading**.
2. `steerToHeading()` nulls the error between current and target heading, wrapped
   to +/-180 deg, and drives the servo proportionally: `STEER_GAIN = 1.0`
   servo-degree per degree of heading error with a 2.0 deg deadband, clamped to
   the asymmetric 64-136 window about the 106 centre (retuned 2026-08-10,
   `58adb1c`; was 1.5 gain / 45-135).
3. **Corner detection** is a rising-edge test, not a threshold test: a corner is
   declared when a side TF-Luna transitions from "wall present" to reading
   **> 150 cm** (`OPENING_CM`). The target heading is then stepped by 90 deg
   toward the opening.

**Why an edge and not a level.** A level test re-fires on every loop iteration
while the opening is still in view, stepping the heading by 90 deg repeatedly and
spinning the vehicle. The edge test fires once per opening.

**Why absolute heading rather than integrated turn rate.** The BNO055 supplies a
fused absolute yaw. A gyro-integrated heading accumulates drift over three laps
and there is no landmark in the Open Challenge to correct against.

---

## 2. Obstacle Challenge — implemented

**Status: landed.** Controller (`src/Round 2/main.cpp`) and Pi runtime
(`src/Round 2/round2.py`) are in this repository. The three integration fixes
that gated the landing are done: the wireless telemetry link is compiled out
behind `ENABLE_BLUETOOTH 0` for rule 11.10 compliance, the BNO055 sits on
verified multiplexer channel 4, and the TB6612 standby line is driven high
unconditionally. The state machine below documents the controller **as
committed** in `src/Round 2/` — not as resident on the vehicle. What is
physically on the ESP32 is whatever was flashed last, which this repository
does not track, so a flash of the committed build precedes any run and the run
log records the revision flashed.

```mermaid
stateDiagram-v2
    [*] --> WAIT_FOR_START
    WAIT_FOR_START --> DRIVING_STRAIGHT : start button (50 ms debounce), heading captured at press

    DRIVING_STRAIGHT --> TURNING : |L-R| > 100 cm for 5 consecutive loops, same direction
    TURNING --> DRIVING_STRAIGHT : raw heading within 6 deg of target, 300 ms cooldown

    DRIVING_STRAIGHT --> OBSTACLE_AVOIDING : RED / GREEN (5-of-7 confirmed, inside height band, not yet pass-side safe)
    OBSTACLE_AVOIDING --> DRIVING_STRAIGHT : CLEAR (10-frame debounce) or 1.5 s dead-man
    OBSTACLE_AVOIDING --> TURNING : corner spike while avoiding (armed 2026-08-11 - MAT-UNVERIFIED)
    OBSTACLE_AVOIDING --> REVERSING : REVERSE (pillar height > 80 px)
    REVERSING --> OBSTACLE_AVOIDING : REVERSE stream silent 250 ms

    DRIVING_STRAIGHT --> ROBOT_STOPPED : 12 turns done and centre LiDAR < 165 cm
    ROBOT_STOPPED --> [*]
```

### The serial protocol, and why it is state-gated

The Pi speaks five messages at 115200 baud: `RED`, `GREEN`, `CLEAR`, `REVERSE`,
and `POS,cx,h` (Kalman-smoothed pillar centre-x and height, every tracked
frame). The active colour is re-sent every 0.5 s as a keepalive; the controller
auto-clears after 1.5 s of silence, so a dead link degrades to heading-hold
instead of a runaway swerve.

Commands are honoured only where they are safe. `RED`/`GREEN` are accepted
while driving straight **or already avoiding** — a mid-avoid colour switch must
flip the swerve, a failure we hit in testing. Everything is ignored during
`TURNING` (a corner is never aborted halfway) and after `ROBOT_STOPPED` (a
stray post-finish detection must never restart the vehicle, rule 9.24).

### Why this shape

- **`DRIVING_STRAIGHT` is the default and every other state returns to it.**
  Any state that cannot make progress falls back to PD heading-hold, which is
  the behaviour that scores worst-case rather than crashes.
- **Avoidance is a gradient, with the field-proven full lock as its boundary.**
  The steer offset is proportional to how far the pillar sits from its
  pass-side safe line in the frame (`offset = KV * error`, floored at a small
  minimum while error remains, clamped to the +/-35 mechanical envelope). Large
  error saturates to exactly the old binary full-lock swerve, which also
  remains the fallback until the first `POS` of each pillar arrives. Field
  evidence is never thrown away — it becomes the clamp.
- **Detection is gated by voting, not by a confidence score.** The calibrated-Lab
  picker has no confidence scalar; a colour must appear in 5 of the last 7
  frames, inside the height band, and short of its pass-side line before a
  command is sent. Holding course remains the safe default.
- **Heading is captured at the start button, not at boot** — with the vehicle
  placed on the mat, so the reference frame is the field. The BNO055 runs in
  IMUPLUS mode (no magnetometer: drive-motor magnets cannot distort yaw), and
  each turn target is stepped +/-90 deg **from the previous target**, so the
  four leg headings stay exactly orthogonal in any reference frame and drift
  cannot accumulate across twelve turns.
- **Corner spikes must persist.** A pillar occluding one side LiDAR can fake the
  left-right asymmetry for a frame or two; requiring 5 consecutive
  same-direction loops rejects it. Turn completion is checked on the raw
  heading — the smoothing filter's ~200 ms lag would overshoot every corner.

### Designed, not yet implemented

**Parking is confirmed in-scope (decided 2026-08-06)** — `PARK_SEARCH` /
`PARALLEL_PARK` states are a commitment, not an option, but they are not in
the committed controller yet. The scoring
table settles it: rule 1.8.3 pays 7 points even for a partial or non-parallel
park, so a crude, conservative attempt strictly dominates a descope (full
rationale: [4 — Decisions](4_systems_and_decisions.md), D7). One of the two
constraints has since been removed: bay **detection** exists — the runtime
picker gained a third calibrated magenta class on 2026-08-12 (§3.1) and
reports bay sightings as telemetry. What is missing is the controller that
acts on them: no state consumes `MAG` and the park states do not exist in
code. The second constraint stands — rule 9.24.7 ends the round on touching a
limiter, which caps how aggressive the manoeuvre may be.

Parking-bay entry geometry, and the tuned value of the gradient gain `KV` —
both wait on the new chassis dimensions and mat time (see
[1 — Mobility](1_mobility.md)).

---

## 3. Detection stack

**Stack of record (2026-08-05): calibrated-Lab colour picker.** One (a,b) chroma
disc per colour in CIELab, sampled interactively at the venue (median + MAD sets
the tolerance, capped), with an L floor and a chroma gate; largest connected
component with extent and aspect gates; 5-of-7 temporal vote; nearest pillar by
lowest box bottom edge. Per-venue calibration is a deliberate reversal of the
fixed published-value-band philosophy — reasoning in
[D6](4_systems_and_decisions.md#d6--neural-detector-superseded-in-the-field-calibrated-per-venue-picker-adopted).
The runtime is landed at `src/Round 2/round2.py` alongside the controller.

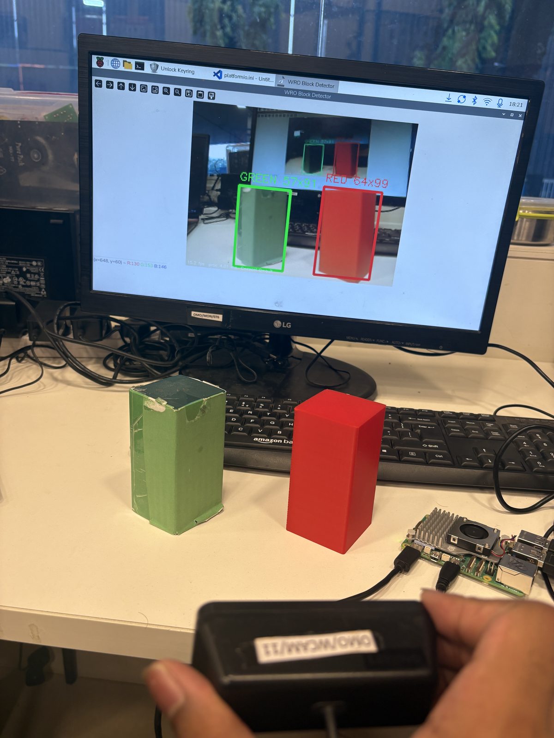
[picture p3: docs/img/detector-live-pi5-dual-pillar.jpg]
Live detection on the Pi 5

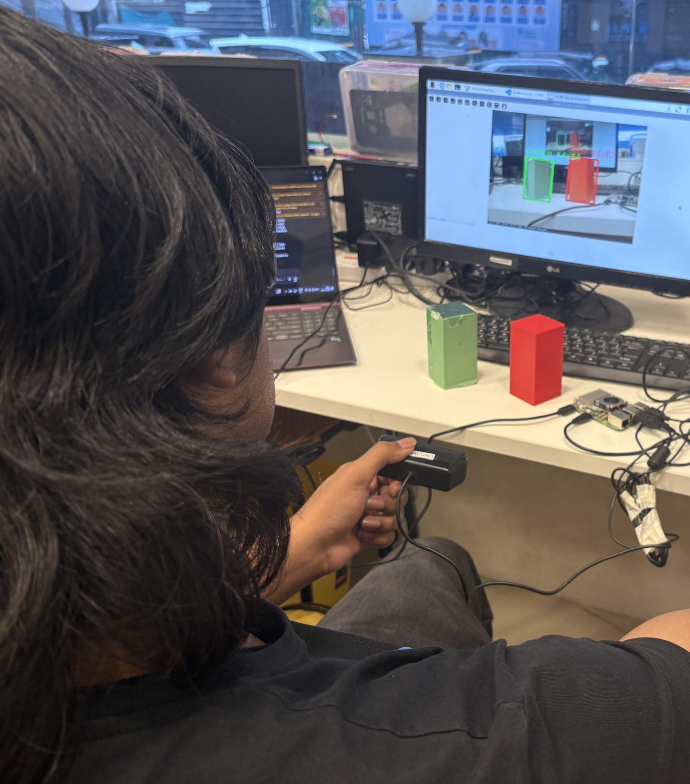
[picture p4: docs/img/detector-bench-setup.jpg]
Bench setup

*Bench test on the Raspberry Pi 5 against physical pillars: dual-pillar frame
classified with per-colour boxes. The overlay's fps and per-frame-ms figures
will be quoted in the metrics section once pinned to the exact build under
test.*

**Superseded (kept as evidence):** `nanodet_lite`, 1,167,660 parameters, 4.52 MB
ONNX — won the val split but did not transfer to real footage. Full write-up and
reproduction steps: [`src/Round 2/detector/README.md`](../src/Round%202/detector/README.md);
selection evidence vs `tiny_pillar`:
[4 — Systems Thinking](4_systems_and_decisions.md#d2--tiny_pillar-111-k-params-rejected-in-favour-of-nanodet_lite-117-m-params).

---

### 3.1 Third class: magenta parking-lot markers (2026-08-12)

The runtime picker calibrates three classes, not two. Magenta was previously
excluded on purpose — as a distractor to veto, since the rules put magenta only
on the parking-lot limitation blocks (200 × 20 × 100 mm, RGB 255, 0, 255) and
nothing in the controller scored for them. Parking is in scope, so magenta is
now calibrated exactly like red and green, on calibration key `3`.

The gates below are magenta-only. The red/green path is unchanged and was
verified bit-identical after the change.

| Gate | Value | Why |
|---|---|---|
| Hard pre-gate | `b* < 126` in u8 Lab (`b* < 0` signed) | magenta is the only one of the three classes with negative `b*` — the mirror of the red `b* > 0` gate |
| Chroma floor | 32 (default 10) | at close range a low-chroma magenta reflection-bleed field on the glossy mat merges with the marker into one large, low-extent blob. The bleed, not the hue, was the failure |
| Morphology | `OPEN` 3 × 3 | severs the bleed from the marker. A `CLOSE` was tried first and falsified — it bridges the bleed *into* the marker |
| Blob selection | extent ≥ 0.40, top-3 candidates, aspect ≤ 8 | two strips per lot, plus edge clipping, mean the largest blob is often not the usable one |
| Calibration tolerance | `max_tol` 22 | the 15 cap exists to keep the red↔green budget apart; magenta's nearest neighbour is far outside it (§4.2) |

The Pi emits `MAG,cx,h,w` at 5 Hz after a 5-of-N confirmation. Width is
appended **last**, so a parser reading the earlier two-field form stays
correct. The ESP32 stores the width and drives no behaviour from it.

---

## 4. Metrics used to validate performance

All figures on the leakage-free group-wise validation split (124 real images).
They belong to the superseded neural stack and are retained as selection
evidence; the *method* — the sweep, asymmetric error costs, failure
decomposition — carries over to the current stack, whose own figures are in
§4.1 below. Raw output for every table in this document is committed under
`docs/eval_raw/`.

### 4.1 The picker's own figures (current stack of record)

Measured 2026-08-08 by `src/Round 2/eval_picker.py`, which imports the detection
functions from `round2.py` **verbatim** — no reimplementation, so what is
measured is the code that runs on the robot. Calibration is fitted with the
shipped `calibrate_color()` on the **train** split only; the val images below
were never used to fit it. Raw: `docs/eval_raw/picker_eval_summary.txt`.

| | pooled calibration | condition-matched calibration |
|---|---|---|
| Detection rate (nearest pillar) | 68.5 % | 63.3 % stills · 100 % video |
| Colour correct, given a detection | 76.5 % | **90.3 %** stills · 80.8 % video |
| Pass-side calls committed | 33.1 % (41/124) | 33.7 % stills · 38.5 % video |
| **Accuracy among committed calls** | 90.2 % (37/41) | **100 % (33/33)** stills · 90.0 % (9/10) video |
| **Wrong-side rate** | 3.2 % | **0.0 %** stills · 3.8 % video |
| Hold course (pillar under the 45 px gate) | 50.8 % | 50.0 % · 23.1 % |
| False detections per empty frame | 0.35 (21/60) | — |
| Latency, 240×240 | 4.6 ms median (desktop, **not a Pi figure**) | — |

**The finding, and it changed race procedure.** Pooling calibration samples
across two acquisition sessions drives red's tolerance to exactly 15.00 — the
`max_tol` ceiling — because the two sessions disagree about what red *is*: their
fitted red centres sit **24.0 apart** in Lab (a,b) (stills a=29.9 b=23.5; video
a=48.5 b=38.7) while the tolerance is only 12–15. One circle cannot cover both,
so the pooled fit lands between them and clips both. Calibrating within a single
condition removes the wrong-side calls entirely on the stills family (0 wrong in
33 committed calls) and lifts colour accuracy 76.5 % → 90.3 %.

This is the measured form of the field failure we recorded on 2026-08-06
("detector fails on slight colour shift"). It is not a defect to be tuned away —
it is a property of thresholding raw colour, and the procedural answer is to
calibrate **at the venue, in the venue's light**, and never reuse a calibration
across lighting. That is what `--calib` JSON persistence exists for: calibrate
once during check time, then run headless from the saved file.

**Honest limits of this table.** The dataset was shot on a different camera than
the robot's, so these numbers validate the *method*, not venue performance.
Still images cannot exercise the 5-of-7 temporal vote, so the false-alarm figure
is per-frame and is therefore an upper bound on what the runtime does. The
co-occurrence arm is the weakest result — 47.1 % among committed calls (8 right,
9 wrong out of 60 composited frames), i.e. a coin flip when two pillars are
visible; those frames are composited rather than photographed, but the direction
matches the known dominant failure and it is why the mid-avoid colour-switch fix
was made a blocker rather than a nicety. Set against that,
[`other/bench-2026-08-05/bench-5.jpeg`](../other/bench-2026-08-05/bench-5.jpeg)
shows the runtime resolving a real red and a real green pillar simultaneously and
correctly on the deployed camera — one frame, so it settles nothing, but it is
reason to treat the composited proxy as pessimistic and to re-measure against
real two-pillar footage.

**Two limits this measurement exposed, both now on the record.** The 4.6 ms is
the hand-rolled NumPy Lab conversion in `round2.py`; `pillar_fast.py` does the
same conversion through `cv2.cvtColor` in 0.43 ms. On Pi-class hardware that
difference decides whether the loop clears 30 fps, and it is the first
optimisation to make if the field run is frame-starved. Second, 50.8 % of val
frames sit below the 45 px swerve gate — the gate is doing most of the work in
this dataset, so the detection numbers above describe a harder regime than the
close-range decisions that actually score.

### Confidence-threshold sweep

Superseded stack. Raw: `docs/eval_raw/nanodet_sweep_raw.txt`.

| thr | val acc | wrong side | no call | both-pillar wrong | false det / empty frame |
|---|---|---|---|---|---|
| 0.30 | 0.941 | 5.9 % | 0.0 % | 11.7 % | 0.350 |
| 0.35 | 0.932 | 5.9 % | 0.8 % | 13.3 % | 0.283 |
| **0.45** | **0.941** | **5.1 %** | 0.8 % | 18.3 % | **0.083** |
| 0.55 | 0.856 | **0.0 %** | 14.4 % | 20.0 % | 0.050 |

### Operating point: 0.45, and why

Chosen from the sweep, not by eye. Three reasons, in order:

1. **Joint-best on real-frame accuracy.** 0.30 and 0.45 tie at 0.941; nothing
   higher exists in the sweep.
2. **It cuts phantom detections on empty frames 3.4x versus 0.35** (0.083 vs
   0.283 per frame) and 4.2x versus 0.30. Most frames on a lap contain no pillar
   at all, so the empty-frame false-alarm rate is weighted more heavily than its
   column position suggests.
3. **Where it loses, it loses on synthetic data.** 0.45 is worse than 0.35 on the
   both-pillar column (18.3 % vs 13.3 %) — but that column is measured on
   **composited** frames, while the columns it wins on are measured on real ones.
   A real measurement outranks a synthetic one.

**When we would move it.** `thr 0.55` gives **zero** wrong-side calls on real
frames, at the cost of holding course 14.4 % of the time. If venue testing shows
that a spurious steer is more expensive than hesitation — for instance if the
vehicle cannot recover its line after a wrong pass — 0.55 is the switch, and it
is a one-line change.

### Failure decomposition

Where the remaining error actually lives:

| Stage | Share |
|---|---|
| Detection — nearest pillar never proposed | **30.0 %** |
| Selection — wrong pillar chosen as nearest | 1.7 % |
| Classification — right pillar, wrong colour | **0.0 %** |

This decomposition is what killed the HSV-rescoring proposal
([D3](4_systems_and_decisions.md#d3--hsv-confidence-rescoring-researched-quantified-rejected)):
colour is already solved, so a colour-based fix has nowhere to go.

---

### 4.2 Magenta class figures

85 frames sampled from two videos of the actual lot markers on the mat, run
through the full `process_frame` path rather than the mask alone. Detection at
tolerance 20: **43/85 → 76/85**.

All nine residual misses are close-approach frames in which the tape's chroma
physically collapses. That range belongs to the front TF-Luna, not the camera.
Distant and mid range are 100 %.

Measured magenta↔red separation in (a\*, b\*) is **46.8** on stills and **55.1**
on video, against tolerances of 22 for magenta and 15 for red — a cross-class
hit is not reachable. This is a different quantity from the 108.4 recorded in
`docs/eval_raw/picker_eval_summary.json`, which is the distance from the
calibrated red centre to the **published** magenta RGB; real tape is duller
than the published colour. Both figures sit far outside every tolerance in use.

The gates were set on phone footage whose auto white balance drifted (a\* 60 →
49 across 22 s), so the figures above are frame-set numbers, not mat
performance. The live, exposure- and WB-locked calibration on key `3` remains
the procedure of record for a run.

---

## 5. Edge cases

| Case | Handling |
|---|---|
| **Magenta parking walls** sit between red and green in hue and defeat a naive hue band | Not a confuser under the calibrated-Lab picker: magenta is its own calibrated class, separated from red by 46.8–55.1 in (a\*, b\*) against tolerances of 22 and 15 (§4.2). Magenta surfaces remain mined into the superseded detector's training negatives. |
| **Two same-colour pillars merge into one blob** under connected components | Nearest pillar is selected by **lowest box bottom edge**, which survives a merge better than box area or height. |
| **Distant pillars** below the `MIN_H` height gate | Deliberately ignored. A pillar too small to measure reliably is a pillar there is still time to react to on a later frame. |
| **Occluded pillar, top clipped** | Selection uses the bottom edge, not the height: clipping eats the top of a pillar while its base stays put. |
| **Both pillars in frame** | Normal on track. Nearest-by-bottom-edge decides. Worst-measured condition — see the sweep. |
| **No detection above threshold** | Hold course. Recoverable; a wrong steer is not. |
| **Mixed 4:3 and 16:9 source images** | Letterboxed, never stretched — stretching would let the model infer class from aspect ratio. |
| **Class list reordered in a config** | Pass-side lookup keyed on class **name**, not index. Loader refuses to start on a mismatch. |

---
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

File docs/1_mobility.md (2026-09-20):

# 1 — Mobility & Mechanical Design

> **Scope:** this document describes the Nationals (August 2026) vehicle. The September rebuild for APAC 2026 is in [`apac_2026_vehicle.md`](apac_2026_vehicle.md).

**Honest status: the vehicle is built to its Round-1 configuration — chassis,
single-servo Ackermann steering, and an N20 drive through a LEGO differential
are physically fitted, with all three TF-Lunas and the IMU mounted.
~~The Raspberry Pi 5 and camera are not yet on the vehicle.~~ (Stale: both were mounted from 2026-08-11.) The gear-ratio, wheel and
battery specs are now read off the hardware and the vendor listing (2026-08-06,
tables below); the working point is still unmeasured, and the first sustained
drive exposed a wheel-retention failure (§3).** The critical-path gap (risk R10)
has narrowed from "no build" to "no measured working point", and this document
does not write around it.

---

## 1. What exists
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

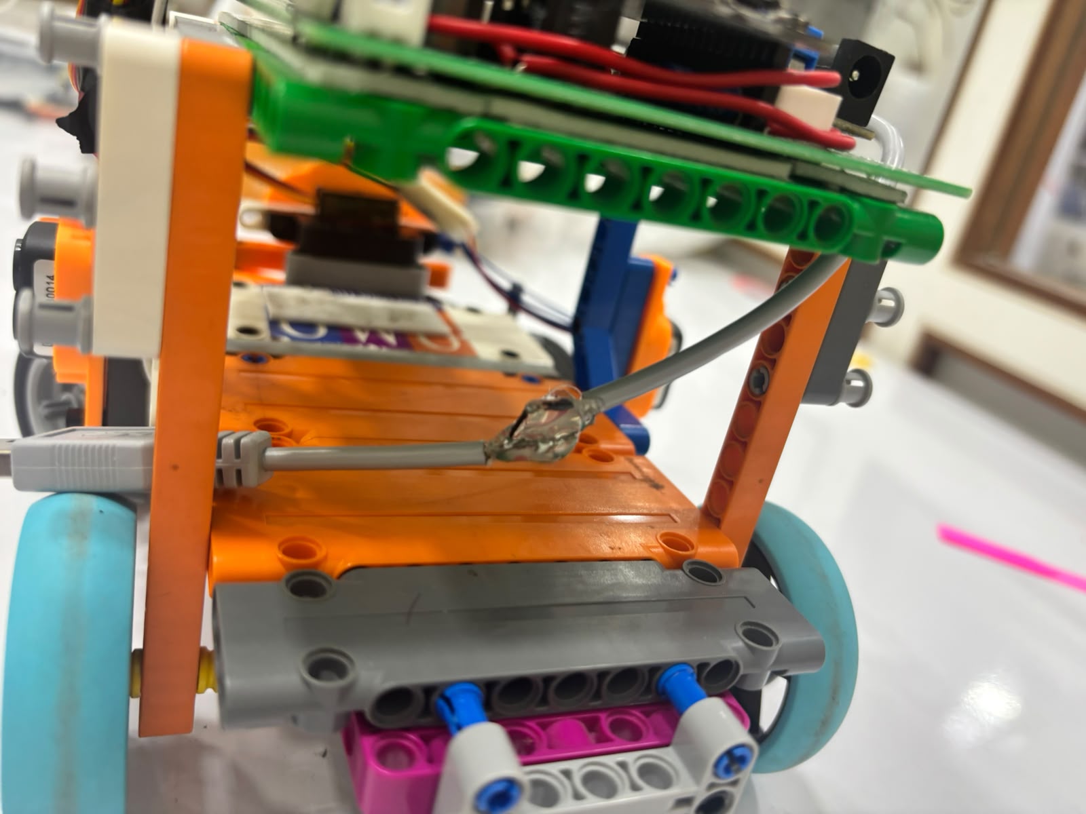
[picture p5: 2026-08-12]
v-photos/detail/chassis-midsection.jpg

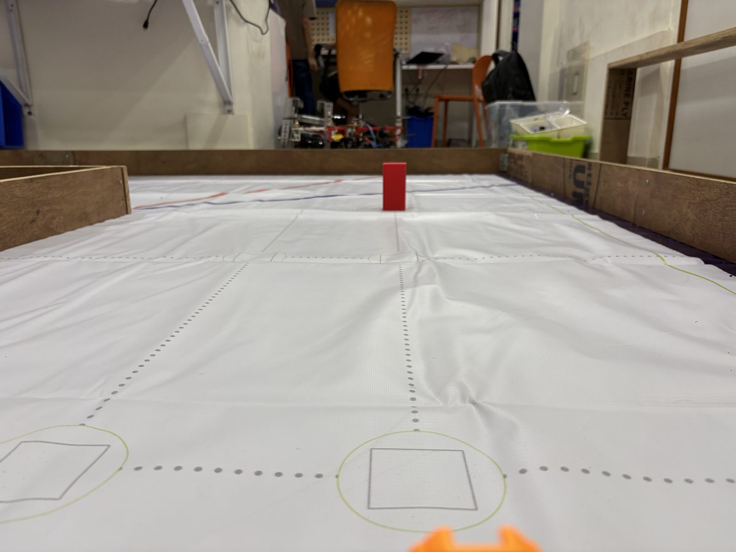
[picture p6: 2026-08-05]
docs/img/camera-pov-far.jpg

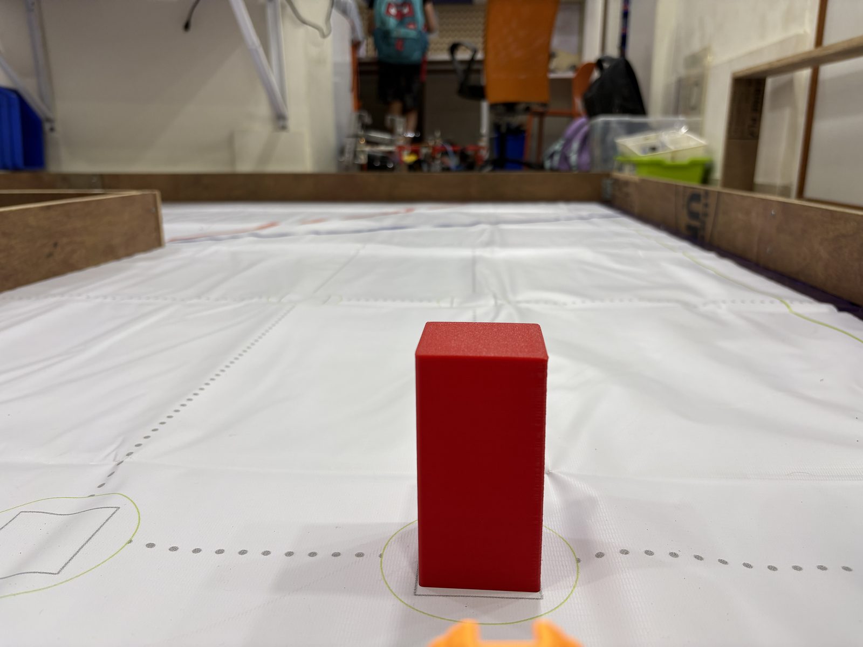
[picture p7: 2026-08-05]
docs/img/camera-pov-near.jpg

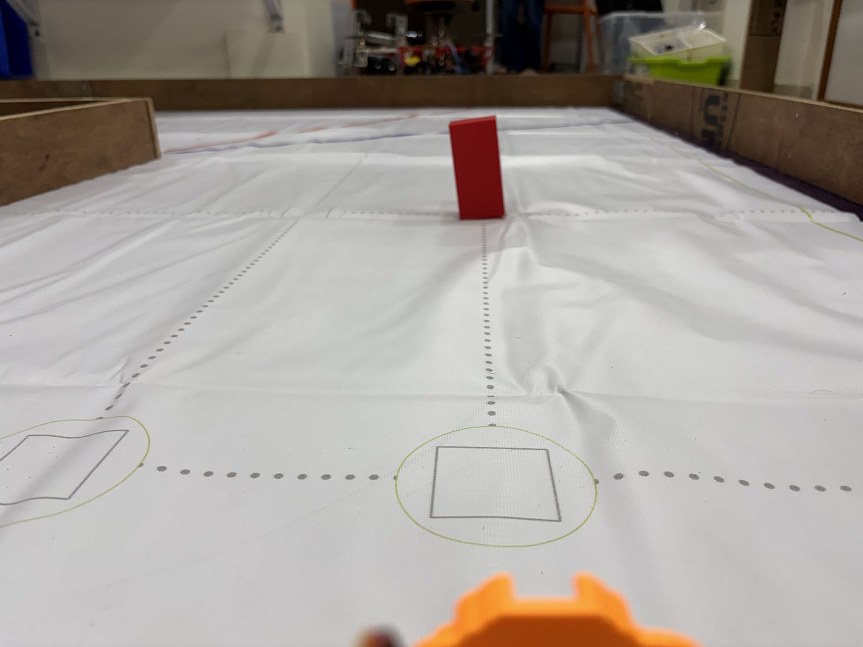
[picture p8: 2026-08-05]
docs/img/camera-pov-mid.jpg

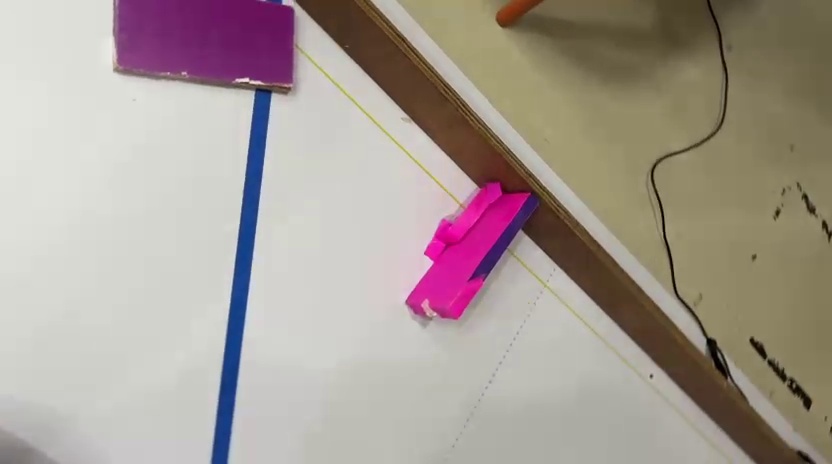
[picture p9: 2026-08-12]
other/magenta-frames-2026-08-12/vidB_f00760.jpg

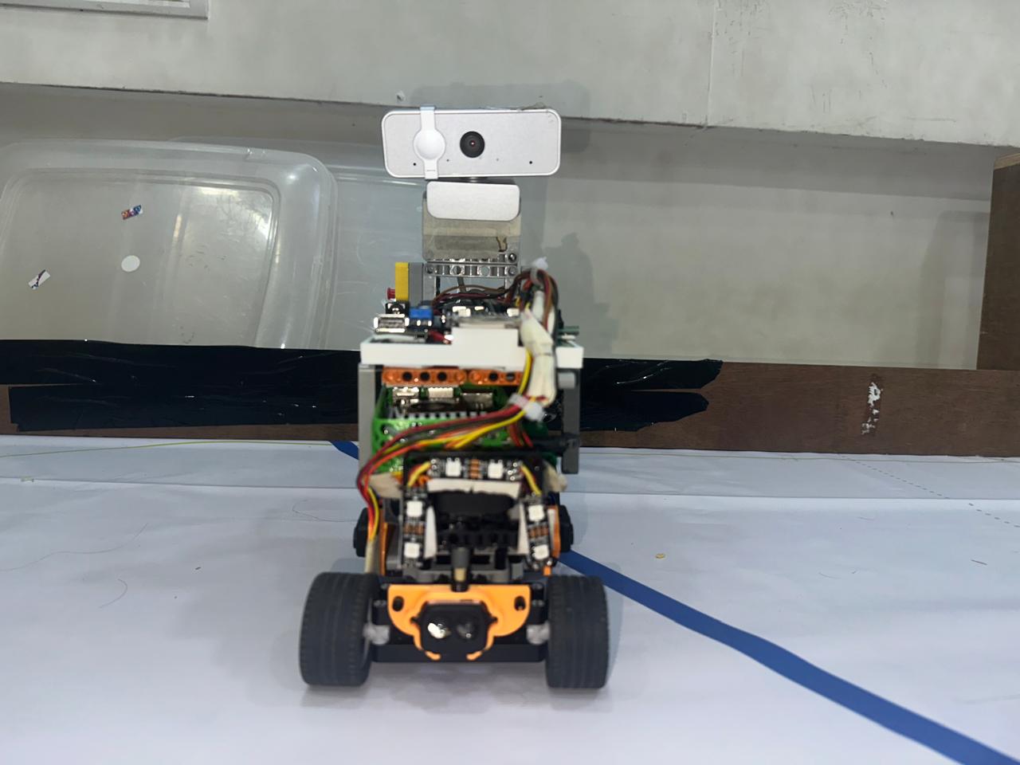
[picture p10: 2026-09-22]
v-photos/apac-2026-09-22/apac-front.jpg

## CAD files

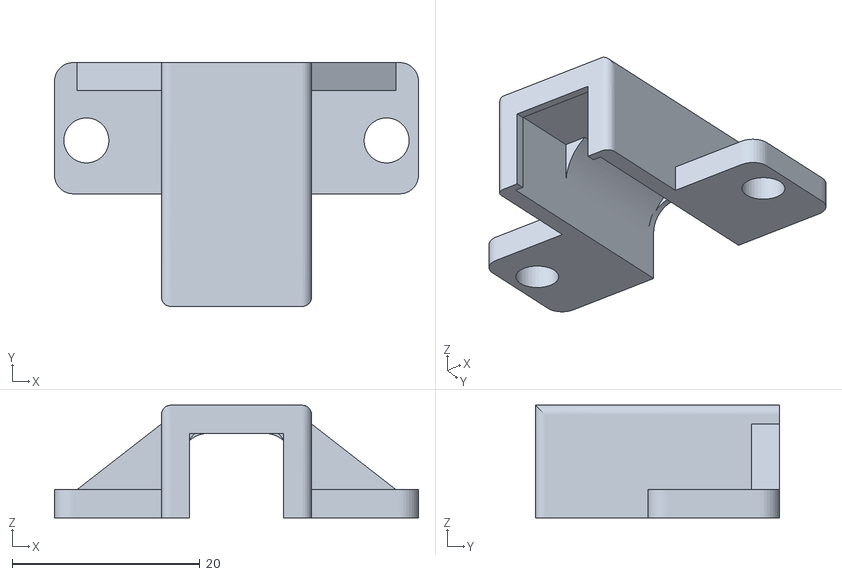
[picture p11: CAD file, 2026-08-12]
models/drive/n20_clamp_lego.stl
38.8 x 26.0 x 12.0

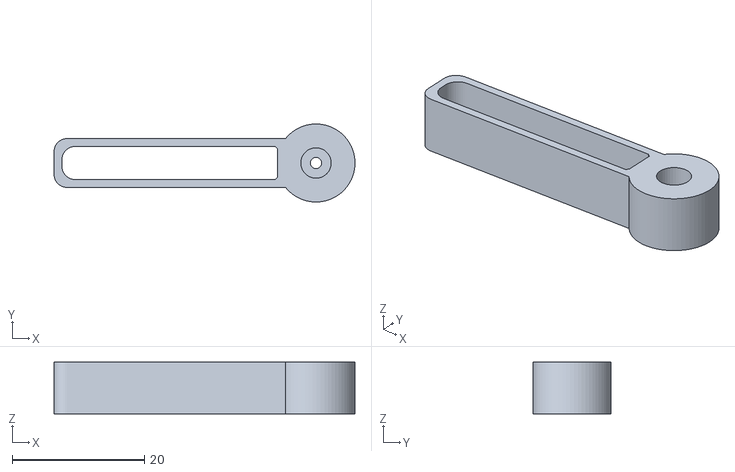
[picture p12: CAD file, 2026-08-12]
models/steering/Horn_Beam_LONG.stl
45.5 x 11.8 x 7.85

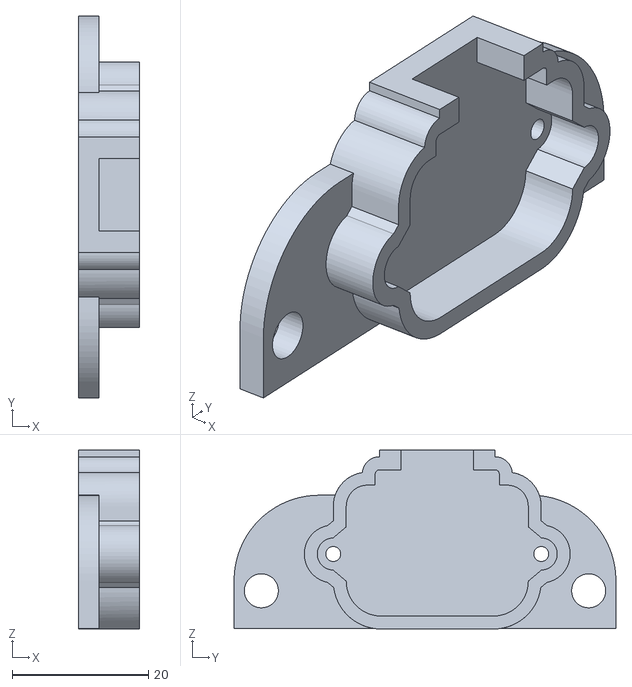
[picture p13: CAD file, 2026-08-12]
models/tf-luna/TF_luna_enclosure_lego.stl
9.00 x 56.0 x 26.3

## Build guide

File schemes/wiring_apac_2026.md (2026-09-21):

# APAC 2026 wiring — power and signals (as built, 2026-09-20)

Current diagram for the September rebuild. It replaces `circuit_diagram_complete_2026-08-11.jpg` (the Nationals vehicle) and adds the WS2812 LEDs on GPIO4, the power switch on the battery lead, the start button on GPIO32 and the MEX drive motor. Pins come from the Nationals firmware and the 2026-09-20 wiring draft and will be re-checked against the APAC firmware when it is committed. All grounds are common (not drawn).

```mermaid
flowchart LR
    BAT["3S LiPo<br/>11.1 V, 2200 mAh"] --> SW["Power switch<br/>(battery lead)"]
    SW --> FCM["Fast-charge module<br/>5 V USB-A out"]
    SW --> BUCK["Buck-2<br/>5 V rail"]
    SW --> DRV["TB6612FNG<br/>VM = pack"]
    FCM -->|"USB-A to USB-C"| PI["Raspberry Pi 5"]
    PI -->|"USB"| CAM["Lenovo 300 FHD camera"]
    PI -->|"USB: data + 5 V"| ESP["ESP32"]
    BUCK -->|"5 V"| TFL["3x TF-Luna"]
    BUCK -->|"5 V"| SRV["MG90 servo"]
    BUCK -->|"5 V"| LED["6x WS2812 LEDs"]
    ESP -->|"3.3 V, GPIO21 SDA, GPIO22 SCL"| MUX["PCA9548A 0x70"]
    MUX -->|"ch0 left, ch3 centre, ch2 right"| TFL
    MUX -->|"ch4"| IMU["BNO055 0x28"]
    ESP -->|"3.3 V"| IMU
    ESP -->|"GPIO13"| SRV
    ESP -->|"3.3 V, GPIO25 AIN1, GPIO26 AIN2, GPIO33 PWMA, GPIO27 STBY"| DRV
    DRV -->|"AO1, AO2"| MOT["MEX motor<br/>6 V rated, 400 rpm"]
    ESP -->|"GPIO4 data"| LED
    BTN["Start button<br/>(rear beams)"] -->|"GPIO32"| ESP
```

Loads on each rail: the fast-charge module feeds the Pi 5, which powers the camera and the ESP32 over USB (600 mA total without USB-PD, see [APAC 2026 vehicle §6](../docs/apac_2026_vehicle.md)); Buck-2 feeds the three TF-Lunas, the servo and the LEDs (up to 0.36 A for the LEDs at full white); the TB6612FNG takes the motor current straight from the pack.

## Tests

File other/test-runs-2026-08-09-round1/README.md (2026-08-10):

# Round 1 (Open Challenge) test runs - 2026-08-09 evening

Two runs on the Open Challenge layout, recorded the same evening. **The firmware
was the same in both** - the revision committed alongside this directory - and
the only deliberate variable is the **inner-wall configuration**: how many of the
extendable centre wall sections were pushed out. That makes this pair the first
controlled comparison in the repository. The
[2026-08-09 obstacle runs](../test-runs-2026-08-09) varied speed at fixed
firmware; the [2026-08-08 runs](../test-runs-2026-08-08) varied firmware and
cannot be compared to anything.

**These are not the competition demonstration videos.** Those are linked from
[`video/video.md`](../../video/video.md) as required. What follows is test
footage retained as engineering record.

| File | Inner-wall configuration | Length | Frame rate |
|---|---|---|---|
| `run-1-two-wall-extensions.mp4` | Two extended sections, on adjacent sides of the centre block | 28.1 s | 31.6 fps |
| `run-2-one-wall-extension.mp4` | One extended section | 29.2 s | 30 fps |

The configuration labels describe what is visible in the footage. They have not
been cross-checked against a measured field layout, so they identify the two
runs relative to each other and are not a claim about which official
randomisation each corresponds to.

No traffic-sign pillars are placed on the driving surface in either run. The
coloured blocks visible inside the centre block are stored there, as in the
2026-08-08 footage.

## What the footage establishes

- Both vehicles circulate the track under their own control for the whole
  recording. No frame at 0.5 s sampling shows the vehicle stalled, wedged, or
  being handled after the start.
- The corridor width differs between the two runs by construction, and the same
  steering constants were used in both. That is the comparison worth having.

## What the footage does not establish

**Neither recording captures the end of a run.** In the final frame of each, the
vehicle is still driving. Nothing here shows the twelfth turn, the
`FINAL_RUN_MS` run-on, or the `motorBrake()` stop, so the lap counter and the
stopping logic remain untested by this evidence. A run is only demonstrated when
the recording continues past the vehicle coming to rest.

Wall contact between sampled frames is also not excluded. Sampling was 2 s over
the body of each run and 1 s over the last eight seconds.

## Measurement attempt that failed, recorded so it is not repeated

Automated trajectory extraction was attempted on both clips and abandoned. Two
methods were tried:

1. **Median-background subtraction.** Fails because the camera is handheld and
   moving. The background model blurs and every static edge registers as motion.
2. **Colour segmentation on the vehicle, with ORB homography stabilisation.**
   Fails because the stored red and green blocks sitting on the centre block
   occupy the same hue range as the vehicle's own colouring, and the tracker
   locks onto them. Stabilisation quality also degrades whenever the operator
   walks through frame.

Both produced trajectories that were plainly wrong on inspection, so no number
derived from them appears above. This is the same conclusion the 2026-08-08
notes reached from the other direction: **video is the wrong instrument for
these measurements.** Serial telemetry is the right one. The firmware already
prints heading, target, servo angle and a `[turn] n/12` line every loop; a
captured log settles lap count, stop behaviour and steering residual directly
and does not depend on camera work.

If video measurement is wanted later, the cheap fixes are a tripod and a strip
of tape on the vehicle in a colour that appears nowhere else on the field.

## Firmware delta in this revision

Relative to the previous `main`:

| Constant | Was | Now |
|---|---|---|
| `SERVO_CENTER` | 90 | 106 |
| `SERVO_MIN_ANGLE` / `SERVO_MAX_ANGLE` | 45 / 135 | 64 / 136 |
| `STEER_GAIN` | 1.5 | 1 |
| `STEER_DEADBAND` | absent | 2.0 deg |
| `DRIVE_SPEED` | 550 | 1000 |
| `FINAL_RUN_MS` | 1500 | 500 |

**The steering correction also changed sign**, from
`SERVO_CENTER + STEER_GAIN * error` to `SERVO_CENTER - STEER_GAIN * error`. That
is the largest change in the diff and it is not a retune: with the previous sign
the loop drove the heading error further open rather than closing it, so the
Round 1 sketch as it stood on `main` could not hold a heading after a turn.

This does **not** explain the failure recorded in the
[2026-08-09 obstacle runs](../test-runs-2026-08-09). Those ran the Round 2
controller, `src/Round 2/main.cpp`, which is a separate implementation with its
own `SERVO_CENTER`, an explicit `INVERT_STEERING` flag and hand-branched signs at
each call site. It does not contain the expression corrected here, so the
`snapToCardinal` boot-heading hypothesis recorded there stands untouched. What
the two implementations do share is that steering sign is chosen by hand in both,
and it has now been found wrong in one of them.

Alongside the sign, `SERVO_CENTER` moved 90 -> 106 and the limits became
asymmetric about it (64 / 136, i.e. -42 / +30), which says the linkage geometry
changed too. Which of the two came first is not recorded.

Behavioural changes: the side LiDARs are muted for 1 s after a corner is taken,
so a single opening cannot re-trigger; heading is read and steering is applied on
every loop including during that mute; a start-button block is present but
commented out.

## Open

1. **Run-completion footage.** Both clips need a retake that runs past the stop.
2. **Serial log.** No telemetry was captured during either run. Until it is, the
   turn count reached in each configuration is unknown.
3. **`FINAL_RUN_MS` is stale.** The `~150 cm` in its inline comment was measured
   at `DRIVE_SPEED 550`. Speed is now 1000 and the value was cut to 500 ms, so
   the run-on distance has changed and has not been re-measured.
4. **`DRIVE_SPEED 1000`** is 98 % duty. There is no headroom left for the
   steering loop to ask for more, and the setting will drift as the pack sags.
5. **No sanity bound on the LiDAR reading.** `readDistance` returns the raw
   16-bit value and only `-1` is treated as a fault. A garbled I2C read that
   decodes large passes `> OPENING_CM` and books a 90 deg turn that never
   happened. The 1 s mute suppresses a repeat, not the first one. A reject band
   outside roughly 2-600 cm costs one line.
6. **Simultaneous left and right openings cancel.** If both fire in the same
   iteration, `targetHeading` nets to zero change, so `trackTurnsAndStop` sees no
   change and counts no turn while the vehicle keeps driving. Whether that can
   occur depends on the inner-wall configuration, which is exactly what these two
   runs varied.
7. **The commented-out start-button block does not work as written.**
   `while (btn == 1) { digitalRead(32); }` never reassigns `btn`, so enabling it
   hangs at boot. It needs `btn = digitalRead(32);` inside the loop. Worth fixing
   before it is needed, since the round requires a no-touch start.

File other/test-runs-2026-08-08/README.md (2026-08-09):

# Test runs — 2026-08-08

Two runs recorded within a minute of each other. **They are two different
software revisions**, and neither matches the revision used in the
[2026-08-09 runs](../test-runs-2026-08-09). Nothing here can be compared against
anything else: each is a record of how one build behaved, and the only variable
is not held constant between them.

| File | Length | Behaviour |
|---|---|---|
| `slow-wobble-first-turn-wall-strike.mp4` | 13.8 s | Drives the first leg slowly, wobbles, and strikes the wall at the first turn |
| `slow-continuous-readjust.mp4` | 20.5 s | Moves very slowly and corrects its steering continuously without ever settling |

Both were shot at 60 fps, which is useful: it is fast enough to resolve steering
corrections if the vehicle is ever filmed close enough to measure them.

## `slow-wobble-first-turn-wall-strike.mp4`

The start button is pressed at about 1.3 s and motion begins around 2.5 s. The
vehicle covers the leg, reaches the first corner toward the end of the
recording, and does not come out of the turn cleanly. The pillars visible along
the outer edge are stored there, not placed on the track.

## `slow-continuous-readjust.mp4`

The distinguishing feature is that the vehicle never holds a heading — it is
correcting continuously for the whole run rather than tracking straight and
occasionally adjusting.

Measured over a 5.1 s window where the camera is steady (10.6–15.7 s), forward
speed is **96 px/s**, which against a vehicle roughly 200 mm long gives about
**0.2 m/s, ±25 %**. That is slow enough to be worth stating as a number rather
than an impression.

**The oscillation frequency could not be measured from this recording, and the
attempt is recorded here so it is not repeated.** The vehicle occupies about
100 px and the lateral residual after removing the path curvature is about
4.5 px RMS, which is the same order as the tracking noise. Two independent
estimators disagreed by a factor of six, and the apparent spectral peak at
1.2 Hz turned out to be the corner frequency of the one-second detrending
window used in the analysis rather than anything the vehicle did.

The frequency is worth having, because a steering limit cycle encodes the loop
delay that produces it. The instrument for that is the serial telemetry log —
steering command against time, sampled at loop rate — not video.

## Open

Which software revision produced each of these runs has been requested from the
team and is not yet recorded. Until it is, these are observations of behaviour
and cannot be attributed to any particular change in the code.

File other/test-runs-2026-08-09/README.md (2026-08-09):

# Drive-speed test runs — 2026-08-09

Two runs on the Obstacle Challenge mat, recorded on the same day at two motor
speed settings. They are kept together because the pair is the evidence: **the
same firmware revision ran in both, and the speed setting is the only thing that
changed** — so the difference in outcome is attributable to speed and not to a
code change. The two [2026-08-08 runs](../test-runs-2026-08-08) are each a
different revision and cannot be compared against these or against each other.

**These are not the competition demonstration videos.** Those are linked from
[`video/video.md`](../../video/video.md) as required. What follows is test
footage retained as engineering record.

| File | Speed setting | Length | Outcome |
|---|---|---|---|
| `speed-400-clean-run.mp4` | 400 | 50.0 s | Runs without intervention for the whole recording |
| `speed-700-leg2-wall-strike.mp4` | 700 | 15.1 s (driving from ≈9.3 s) | Strikes the inner block after the first turn |

## What the failing run shows

Measured from the recording (30 fps):

| Time | Event |
|---|---|
| ≈9.3 s | Motion begins; setup and handling occupy everything before this |
| 10.2 – 12.2 s | Leg 1, straight and stable, tracking parallel to the wall |
| 12.4 – 13.0 s | First turn executes at the corner |
| ≈13.3 s | Heading continues past the new leg direction instead of settling |
| ≈13.6 s | Contact with the inner block corner |
| 13.6 – 15.0 s | Stationary against the block |

The vehicle reaches the inner wall roughly 1.1 s after the turn. The corridor is
1000 mm wide, so from mid-corridor there is about 500 mm of lateral margin to
lose. Crossing that in 1.1 s implies a post-turn heading error in the region of
30–40°, which is the useful part of the measurement: a steering loop with too
much gain oscillates by a few degrees and diverges gradually, whereas an error of
tens of degrees held steadily is a wrong heading *target*, not a poorly damped
one.

## Candidate causes, in the order they are worth testing

1. **Heading reference.** If `snapToCardinal` is resolving to absolute compass
   points while the IMU booted at an arbitrary magnetic heading, leg 1 is correct
   by construction — it *is* the boot heading — and every later leg inherits the
   offset between the boot orientation and the absolute grid. That predicts
   precisely what the recording shows: a clean first leg, then a wall strike on
   the second. It also explains why speed matters without being about speed: the
   error exists at both settings, but at 400 the wall-following correction has
   the time and distance to recover, and at 700 it does not.
2. **Speed-invariant steering gain.** Yaw response scales with forward speed, so
   400 → 700 raises effective loop gain by about 1.75×. Adequate damping at the
   lower setting can become oscillatory at the higher one with no code change.
3. **Loop latency.** Any fixed delay costs proportionally more distance at higher
   speed. The known contributor is the per-loop telemetry line: roughly 120
   characters at 115200 baud is about 10 ms of blocking transmission inside a
   nominally 20 ms loop.

## The test that separates them

Start the vehicle deliberately rotated 30–40° away from the first leg direction
and run at **400**. Cause 1 depends on boot orientation and not on speed, so if
the vehicle fails at the low setting when started rotated, the heading reference
is confirmed and causes 2 and 3 are not what is being observed. If it runs
cleanly, attention moves to gain and latency.

Serial telemetry captured during a failing run would also resolve it directly,
since the heading target is printed each loop and a target that does not match
the wall direction is visible in the log.

## Open

The firmware revision flashed during these runs is not recorded. Until that is
confirmed, the first cause above is a hypothesis consistent with the recording
rather than a diagnosis, and no entry has been made in the risk register on the
strength of it.

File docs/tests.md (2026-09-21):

# Testing workflow

What is tested, by what command, and what result blocks a release.

Anything below marked **not yet run** is named as such. No result is quoted for a
test that has not been executed.

> **Scope:** sections 2–8 record the Nationals (August 2026) stack. The APAC 2026 power and drive bench is §10.

---

## 1. Test levels

| Level | Runs on | Needs hardware | Frequency |
|---|---|---|---|
| **T1** Data integrity | Desktop | No | Every time the dataset changes |
| **T2** Model evaluation | Desktop | No | Every training run |
| **T3** Operating-point sweep | Desktop | No | Every training run |
| **T4** Deploy-graph parity | Desktop | No | Every ONNX export |
| **T5** On-target latency + thermal | Raspberry Pi 5 | Yes | Before any Pi latency claim |
| **T6** Firmware bench | ESP32 + sensors | Yes | Every firmware change |
| **T7** Track | Full vehicle | Yes | **Unblocked 2026-08-08** — drive integrated; six recordings in `other/`; logged run-to-stop pending |

---

## 2. T1 — Data integrity

**Why it exists:** it was written *after* a leakage audit found the validation set
was measuring memorisation — 25 duplicate image stems across the split boundary
and 27 of 29 validation second-buckets shared with training. See
[D5](4_systems_and_decisions.md#d5--data-leakage-audit-our-own-validation-numbers-invalidated-and-rebuilt).

```bash
cd "src/Round 2/detector"
python tools/make_split.py --root <dataset>
```

**Pass criteria**

| Check | Requirement |
|---|---|
| Duplicate stems across split | 0 |
| Validation capture-buckets also present in train | 0 |
| Split sizes | 473 train / 124 val, group-wise by capture bucket |

**A failure here invalidates every downstream number.** It does not adjust them.

---

## 3. T2 — Model evaluation

```bash
python eval_nanodet.py
```

Reports, on the leakage-free validation split: macro F1, pass-side decision
accuracy, wrong-side rate, no-call rate, false detections per empty frame, and
the both-pillar subset.

**Pass criteria (current shipping model as the floor):** macro F1 >= 0.898,
decision accuracy >= 0.941. A candidate that does not clear the shipping model on
both does not ship.

**Label discipline:** the both-pillar rows are measured on **synthetic
composites** — no real image in the dataset contains a red and a green pillar at
once. Every report of those rows must say so.

---

## 4. T3 — Operating-point sweep

```bash
python decide_nanodet.py --sweep
```

Sweeps the confidence threshold over 0.30-0.55 and reports accuracy, wrong-side,
no-call, both-pillar wrong-side and false detections per empty frame at each
point. The threshold is set from this table, never by eye. Current operating
point and the argument for it: [3 — Software](3_software.md#operating-point-045-and-why).

**Pass criterion:** the chosen threshold must be justified in writing against at
least one competing threshold in the same table.

---

## 5. T4 — Deploy-graph parity

```bash
python export_nanodet.py
```

The export drops NanoDet-Plus's auxiliary training head. Training graph and
deploy graph are therefore different objects, which is exactly the confusion that
produced a falsified prediction once already
([D4](4_systems_and_decisions.md#d4--a-prediction-we-made-twice-and-got-wrong-twice)).

**Pass criteria**

| Check | Requirement |
|---|---|
| ONNX output shape | `(1, 2125, 34)` |
| Input | fixed 320 x 320, opset 11 |
| Class list | `["green", "red"]` — loader must refuse a mismatch |
| Decision agreement, ONNX vs PyTorch on the val split | identical pass-side call on every frame |

---

## 6. T5 — On-target latency and thermal — **not yet run**

```bash
onnx2ncnn pillar_nanodet320.onnx pillar.param pillar.bin
ncnnoptimize pillar.param pillar.bin pillar-opt.param pillar-opt.bin 0
benchncnn 20 4 0 -1 1
```

Latency and **temperature and sustained clock** are captured in the *same* run.
A peak-throughput number taken from a cold board does not describe a three-lap
run — that is risk R5.

**Pass criteria:** end-to-end perception latency compatible with the pass-decision
look-ahead of 327-567 mm at race speed, and no thermal throttling observed across
a 15-minute sustained run.

**Until this test has run, no Raspberry Pi 5 latency figure exists for this
model.** The ~30 fps number in earlier notes is a different model (YOLO26s @ 224,
9.47 M params); the 24.6 ms figure is fp32 on x86.

If T5 fails, the fallback is `tiny_pillar` at 111 K parameters — identical
pass-side interface, measured accuracy cost documented in
[D2](4_systems_and_decisions.md#d2--tiny_pillar-111-k-params-rejected-in-favour-of-nanodet_lite-117-m-params).

---

## 7. T6 — Firmware bench

| Test | Method | Pass criterion |
|---|---|---|
| I2C mux channel select | Read all three TF-Luna channels with only one sensor connected | Only the connected channel returns a plausible range |
| BNO055 calibration gate | Power-on, watch calibration status registers | Heading capture does not occur until status is calibrated |
| Servo travel | Command 45 / 90 / 135 deg | Mechanical travel matches, no binding at either limit |
| Heading hold | Rotate the chassis by hand, release | Servo counter-steers proportionally; saturates at 30 deg of error |
| Corner edge detection | Present and remove a wall in front of a side LiDAR | Target heading steps 90 deg exactly **once** per edge, not repeatedly |

The last one is the important one: it is the test that distinguishes a rising-edge
implementation from a level test, and a level test spins the vehicle.

---

## 8. T7 — Track — **unblocked 2026-08-08**

The drivetrain is integrated ([1 — Mobility](1_mobility.md)) and the vehicle
drives: six test recordings are committed under [`other/`](../other) — the
2026-08-08 pair, the 2026-08-09 speed pair, and the 2026-08-09 Open-Challenge
controlled pair. None yet captures a complete run through the autonomous stop,
and **no serial-telemetry log has ever been recorded** — the first logged
run-to-stop (`tools/serial_log.py`) is the release-blocking T7 result.

Still planned: repeated corner-exit runs measuring understeer at the chosen
speed, and a full three-lap Open Challenge run. The corner-exit test is the one
expected to change the mechanical design.

---

## 9. Regression policy

When the model changes, re-run **T1 -> T2 -> T3 -> T4 -> T5** in that order. T2
and T3 results are not comparable across different splits, so T1 must pass first.

Tables and plots in `docs/` are currently transcribed from test output by hand,
which is exactly how documentation drifts away from data. The mitigation — a
generator under `docs/figures/` that re-derives every table from the raw results
— is specified but **not yet written**. Risk R9 stays open until it is.

---

## 10. APAC 2026 — power and drive bench (2026-09-21)

The predictions were written down before the bench session and compared afterwards. Pack at 12.3 V; ammeter in series on the named lead; `SPEED = 210`.

| Reading | Predicted before | Measured | Result |
|---|---|---|---|
| Buck-2 input, idle, LEDs on | 0.10–0.17 A | 0.12 A | inside |
| Buck-2 input, servo sweeping | 0.15–0.30 A | 0.21–0.29 A | inside |
| Motor wire, rear wheels lifted | 0.25–0.45 A | 0.33 A | inside |
| Rear wheel speed, lifted | 370–490 rpm | 422 rpm | inside |

Check after the fact: the motor model fitted to these readings and the stall current ([APAC vehicle §3](apac_2026_vehicle.md)) gives 3.37 s for a 3 m standing start; the measured time is 3.36 s. The model was fitted after that run, so this is a consistency check, not a prediction.

**Not yet run:** the fast-charge module and Buck-2 rating labels, the turning circle, the motor temperature after a full run, `vcgencmd get_throttled` after a full run.

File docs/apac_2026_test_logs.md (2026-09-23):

# APAC 2026 test logs

**Scope.** What the car's own logs record from 15 to 23 September 2026: 260 runs of `main.py` (`round2_run_*.csv`, one row per telemetry sample and one per event, written when `ENABLE_RUN_CSV_LOGGING = True`) and 32 attempts of `parallel_parking.py` (`parking_run_*.csv`, `ENABLE_RUN_LOGGING = True`). Every figure here is computed from those files by [`run_metrics.py`](../src/apac-2026/tools/run_metrics.py). The per-run summary is [`data/run_summary_2026-09.csv`](data/run_summary_2026-09.csv), the parking attempts are in [`data/parking_runs_2026-09-20/`](data/parking_runs_2026-09-20/), and [`data/example_full_run_20260919_192712.csv`](data/example_full_run_20260919_192712.csv) is the fastest full run, whole. The code was tuned from day to day, so each day's figures belong to that day's settings.

## 1. Full runs from the parking lot

A run counts here when it starts with the parking exit (first state PARKING_EXIT_DIRECTION). It reached the twelfth corner when `corner_counter` reached 12; the time is counted from the first drive command. Runs the team stopped by hand are included, so the counts are attempts, not a success rate.

| Day | Runs | Reached the 12th corner | Time to the 12th corner, s: median (range) |
|---|---|---|---|
| 15 Sep | 22 | 1 | 241 (241–241) |
| 16 Sep | 53 | 2 | 225 (201–248) |
| 17 Sep | 15 | 2 | 206 (204–208) |
| 18 Sep | 39 | 9 | 180 (165–190) |
| 19 Sep | 51 | 10 | 167 (154–184) |
| 20 Sep | 7 | 3 | 176 (168–180) |

From 15–17 to 18–20 September the time to the twelfth corner fell from 201–248 s to 154–190 s (median 176 s over 22 runs); 14 of those 22 runs reached the twelfth corner inside 180 s, the length of a round.

## 2. Why full runs stopped, 18–20 September

The code prints a reason with every FAULT. Reasons in the full runs of 18–20 September:

| Reason | Runs |
|---|---|
| corner clearance reverse made no reliable progress | 7 |
| parking-exit forward heading alignment timeout | 4 |
| front reached 5 cm before parking alignment | 1 |
| unknown Round 2 state STRAIGHT | 1 |
| parking-exit reverse heading alignment timeout | 1 |
| red approach exceeded 4s without reaching distance trigger | 1 |

The most frequent, the corner-clearance reverse that made no progress, is the stall of a car pressed against a wall at a corner.

## 3. Parking

**U-turn parking-in in `main.py`, 17 September.** 24 test runs of the U-turn routine; 0 reached COMPLETE. The faults were clearance limits during the U-turn (U-turn forward clearance only N cm: 5; U-turn side clearance only N cm: 3; U-turn heading did not complete; progress=N: 1). Earlier that evening, 10 runs of the timed routine (reverse at full left lock, then right) reached COMPLETE in 9; the log cannot show whether the car ended inside the space.

**`parallel_parking.py`, 20 September.** 32 attempts from 14:36 to 17:35; 15 reached COMPLETE, in a median of 31 s (20–88 s). In the last session, from 16:30, 7 of 11. The attempts that did not finish stopped in TRACK_OPENING (5), ALIGN_VIRTUAL_CUTOUT (5), ENTER_SPACE (3), PARALLEL_ALIGN (2), PASS_LAST_PILLAR (1), FAULT (1).

**Three laps, then parallel parking, 20 September.** In 3 runs `main.py` handed over after the twelfth corner (PARKING_PARALLEL_HANDOFF) and `parallel_parking.py` took over; 2 of them ended parked:

| Start | Time to the 12th corner, s | Parking | From the first drive command to the end, s |
|---|---|---|---|
| 17:12 | 168 | COMPLETE after 58 s | 226 |
| 17:26 | 180 | TRACK_OPENING after 13 s | 193 |
| 17:32 | 176 | COMPLETE after 88 s | 264 |

At those speeds three laps plus parking took longer than a three-minute round.

## 4. After the side rollers came off, 22 September

7 short runs in the evening, each started on a straight (DETECT_DIRECTION) with a 2-corner limit, as the counters show; 5 reached COMPLETE. CORNER_CLEARANCE_RECOVERY ran in 5 of them, and in 5 the car went on to make its turn.

## 5. What the logs do not show

- Whether a pillar or a wall was touched: the logs record states, distances and commands, not contacts.
- How squarely the car ended in the parking space.

## 6. Performance videos

| Challenge | Video | Run |
|---|---|---|
| Open Challenge | [youtu.be/PbOQJ54wr-0](https://youtu.be/PbOQJ54wr-0), 33 s | India National Championship, August 2026 (first vehicle) |
| Obstacle Challenge | [youtu.be/dBjqMQ-jRBA](https://youtu.be/dBjqMQ-jRBA), 100 s | India National Championship, August 2026 (first vehicle) |

Additional footage: [`video/apac-2026-obstacle-run.mp4`](../video/apac-2026-obstacle-run.mp4), 3 min 19 s, shows the APAC vehicle on the practice mat, about 20 September: from the parking lot, three laps (12 corners), then a stop after the twelfth corner.

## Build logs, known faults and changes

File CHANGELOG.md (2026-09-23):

# Changelog

Entries below v0.1.0 onwards are generated by `release-please` from
[Conventional Commits](https://www.conventionalcommits.org/) — **do not edit by
hand.** See [`docs/5_reproducibility.md`](docs/5_reproducibility.md#5-versioning-and-releases).

## [0.6.0](https://github.com/teddriveomo/wro-2026-future-engineers/compare/wro-2026-future-engineers-v0.5.1...wro-2026-future-engineers-v0.6.0) (2026-09-23)

### Features

* **apac:** main.py hands over to the parking modules; code and firmware from the coach's working copy of 2026-09-23; journal rev 5 ([39201fe](https://github.com/teddriveomo/wro-2026-future-engineers/commit/39201feb079986bdccd42d674d3246b10f68bad6))
* **apac:** Open Challenge firmware and the parking camera calibration from the final code; docs checked against it ([51ef93f](https://github.com/teddriveomo/wro-2026-future-engineers/commit/51ef93f07720556eefaefb145f6cc1242053c53d))

### Documentation

* team roster - Deeyan Mehta (electronics), full name; journal rebuilt ([3a27cef](https://github.com/teddriveomo/wro-2026-future-engineers/commit/3a27cef50828605e275073bf9a8cfbb5c4affa29))

## [0.5.1](https://github.com/teddriveomo/wro-2026-future-engineers/compare/wro-2026-future-engineers-v0.5.0...wro-2026-future-engineers-v0.5.1) (2026-09-23)

### Documentation

* **journal:** APAC 2026 edition of the engineering journal (rev 4), built from the repository's docs ([e75ae9c](https://github.com/teddriveomo/wro-2026-future-engineers/commit/e75ae9c92e5ec78db8e345abc0b90d9b0211efd1))

## [0.5.0](https://github.com/teddriveomo/wro-2026-future-engineers/compare/wro-2026-future-engineers-v0.4.0...wro-2026-future-engineers-v0.5.0) (2026-09-23)

### Features

* **apac:** add the parking modules (parallel and direct entry) as standalone scripts ([7908149](https://github.com/teddriveomo/wro-2026-future-engineers/commit/79081493585a3648c76a75598d1e8ac2f9d81b37))
* **apac:** main.py updated to the 2026-09-18 version the car runs, with its changes documented ([4b57716](https://github.com/teddriveomo/wro-2026-future-engineers/commit/4b577168490cf8caa1007662e862a3cc1a38556f))

### Documentation

* **apac:** colour calibration method at the venue (one practice round on the mat) ([9f2ea22](https://github.com/teddriveomo/wro-2026-future-engineers/commit/9f2ea2232600d81b0aaa95c80de2c95c67d86f10))
* **apac:** detection pipeline, decisions with evidence, parallel parking at APAC, live-view figures ([a0b3625](https://github.com/teddriveomo/wro-2026-future-engineers/commit/a0b36254bd93709a8d6fc53e1eead0ca39324006))
* **apac:** Obstacle Challenge state machine of main.py - diagrams, thresholds, edge cases, limits ([c563b4a](https://github.com/teddriveomo/wro-2026-future-engineers/commit/c563b4a7cf2f94459733bfee0581e44518219e47))
* **apac:** six-view photos of the APAC vehicle (2026-09-22); side rollers removed ([1aef17a](https://github.com/teddriveomo/wro-2026-future-engineers/commit/1aef17a6f24bf0fdd7f515f60c9a37629032e874))
* **photos:** name the informal team photo and correct the README that called it outstanding ([ef8efd2](https://github.com/teddriveomo/wro-2026-future-engineers/commit/ef8efd2537b951fab1e72e9fe0505a793771dfa7))

## [0.4.0](https://github.com/teddriveomo/wro-2026-future-engineers/compare/wro-2026-future-engineers-v0.3.0...wro-2026-future-engineers-v0.4.0) (2026-09-21)

### Features

* **apac:** add the APAC 2026 competition code (Pi main.py, ESP32 firmware, calibration tools) ([7c18fe3](https://github.com/teddriveomo/wro-2026-future-engineers/commit/7c18fe3aa31a9c9e60aacf73ace82b4341f76335))
* **detector:** 3-class yolo26n v2 weights + ONNX, training/eval harness, Pi capture tool ([62836cc](https://github.com/teddriveomo/wro-2026-future-engineers/commit/62836ccfb4bcb52bb9173afd0484b1e601d6748d))
* **round2:** commit competition weights in-folder + provenanced local eval; docs/4 competition-stack decision note ([bbfa34c](https://github.com/teddriveomo/wro-2026-future-engineers/commit/bbfa34c2ca67ef2706c3fdc149ac279aa844e1bf))
* **round2:** competition stack for Nationals - grid/pause-pass firmware (test.cpp) + Pi detector (detecttor.py) ([b715a4b](https://github.com/teddriveomo/wro-2026-future-engineers/commit/b715a4b66ec672680aa59b899ba766f1de90a215))
* **round2:** Round-1-lineage obstacle firmware + Pi vision sender ([41088c3](https://github.com/teddriveomo/wro-2026-future-engineers/commit/41088c3d3152ec7760a100b0aae9fca832599f37))
* **tools:** add wro_capture.py v1.2 - Pi dataset capture rig (Picamera2+OpenCV, key/GPIO trigger, session-tagged, --shutter pins exposure) ([2ad3f84](https://github.com/teddriveomo/wro-2026-future-engineers/commit/2ad3f843e2d9a09bfbc0eb0b6c9f9c823f0202b1))

### Bug Fixes

* **round2:** bound the bay-exit reverse leg by the forward leg it follows ([429c5f0](https://github.com/teddriveomo/wro-2026-future-engineers/commit/429c5f08e4e79b6d317072519de716a06f4b0b98))

### Documentation

* add final Engineering Journal (rev 3), retire draft, index it in README ([8ef96b4](https://github.com/teddriveomo/wro-2026-future-engineers/commit/8ef96b464154d46dec9684acc505dfc7e088b44e))
* **apac:** full write-up - weight and balance, drive voltage, camera geometry, new failure points ([fae26ce](https://github.com/teddriveomo/wro-2026-future-engineers/commit/fae26ce58d7bcb36d37937794154554e0e7a2a6c))
* **apac:** measured drive and power budget, observed front-stop failure, centre TF-Luna on mux ch3 ([598b786](https://github.com/teddriveomo/wro-2026-future-engineers/commit/598b7863e952ad6470bd8b0d131fe2d565236080))
* **apac:** round the pillar-separation angle correctly (12.45 deg is 12.5) ([a061f58](https://github.com/teddriveomo/wro-2026-future-engineers/commit/a061f58480587e6d7cbe4ab853e06416d085c191))
* close pre-competition measurement rows (team check 2026-08-24, consistent with derived/datasheet figures) ([6dd94ba](https://github.com/teddriveomo/wro-2026-future-engineers/commit/6dd94baea40fd5f57a4c608b605efa64aa905605))
* correct the APAC delta - battery and power path are unchanged since Nationals ([9b4f87c](https://github.com/teddriveomo/wro-2026-future-engineers/commit/9b4f87c31ef514a7f56c08c8fda03a960d7d9c8b))
* date docs/3 and point to the flashed competition stack ([9848fa9](https://github.com/teddriveomo/wro-2026-future-engineers/commit/9848fa95743dbab47c7d6e8c1b7633e36ce8224b))
* document the APAC 2026 rebuild; scope docs 1-3 to Nationals ([8efc360](https://github.com/teddriveomo/wro-2026-future-engineers/commit/8efc360028f03af8e0c3e5fd8c0962a108324b80))
* **models:** add APAC 2026 chassis build instructions (84 steps) ([da98d6d](https://github.com/teddriveomo/wro-2026-future-engineers/commit/da98d6d709162773e4540d65a1d930261e1ae32c))
* **photos:** add APAC 2026 working photos (2026-09-20) ([a41fca0](https://github.com/teddriveomo/wro-2026-future-engineers/commit/a41fca0fdc4ff1e01e9def5f30a4d4d8bda78315))
* **readme:** add per-member role attribution ([69cc9b5](https://github.com/teddriveomo/wro-2026-future-engineers/commit/69cc9b595261c176731e30391ee47cd16e118a38))
* remove contradictions - camera-height claim, power-budget status, photo labels, journal scope ([f10734a](https://github.com/teddriveomo/wro-2026-future-engineers/commit/f10734aad7559dc47a37c4d066b9854ebca05898))
* **schemes:** APAC 2026 wiring diagram ([8117988](https://github.com/teddriveomo/wro-2026-future-engineers/commit/811798883756a8beee675d28f416a3e84d5bad52))

## [0.3.0](https://github.com/teddriveomo/wro-2026-future-engineers/compare/wro-2026-future-engineers-v0.2.0...wro-2026-future-engineers-v0.3.0) (2026-08-14)

### Features

* add drive-motor control module + bring-up sketch (3 driver modes, pins-at-top config) ([3943be4](https://github.com/teddriveomo/wro-2026-future-engineers/commit/3943be4e85b0707aef0fd7006dbe0adf2c3356ac))
* **detector:** 3-class yolo26n@320 ONNX + runner, labelled NOT DEPLOYED - in-domain mAP50-95 g.859/r.792/m.820 (staged singles, 85-img val); picker remains stack of record pending benchncnn + concurrent-load on Pi ([f7aa2cd](https://github.com/teddriveomo/wro-2026-future-engineers/commit/f7aa2cd79898f1fb38cb45a3c31f0c51ad85e2c0))
* **detector:** commit magenta measurement raws - 85 mat frames + 132 labels, analysis tools, 3-class training notebook ([fb8f8a6](https://github.com/teddriveomo/wro-2026-future-engineers/commit/fb8f8a69582d2695467f1f22fb68002fb7d54c95))
* **docs:** measure the picker and commit raw evaluation output ([5dc9e90](https://github.com/teddriveomo/wro-2026-future-engineers/commit/5dc9e904d4e797252ac18e2ddbb5ff7d62f79b1a))
* **models:** N20 clamp STL (team re-model, Fusion 360) + 69-page build-instructions PDF; README rows updated, shipped placeholders removed, OMO/WCAM/11 designation reconciled ([63626c4](https://github.com/teddriveomo/wro-2026-future-engineers/commit/63626c46d5b21d505f7318eeb33d76022c039130))
* **models:** original CAD (TF-Luna mount, steering horn) + initial LEGO design ([f1c227e](https://github.com/teddriveomo/wro-2026-future-engineers/commit/f1c227e86a248ebd76816b0ea1e954fbfdb76c0f))
* **models:** the LEGO design files are the CURRENT chassis - relabelled ([ee6c544](https://github.com/teddriveomo/wro-2026-future-engineers/commit/ee6c544325234c5c4e15c670eb30fc1fd83a3e74))
* **other:** 14-photo Fluke bench evidence for the measured power rows - pack label 2200 mAh 60C photo-backed; 5 V probe-point ambiguity documented, row 4 deliberately left empty ([3e6e7d5](https://github.com/teddriveomo/wro-2026-future-engineers/commit/3e6e7d505d135e5c28de82491d182111cd7703af))
* Round 2 stack lands - calibrated-Lab picker runtime + ESP32 controller ([4375956](https://github.com/teddriveomo/wro-2026-future-engineers/commit/43759560d0d484ea6f218579813ad3a53af829bd))
* **round1:** land canonical N20/TB6612 drive integration ([406e315](https://github.com/teddriveomo/wro-2026-future-engineers/commit/406e3150e3e39b27a1a4c3ced907065c710e081b))
* **round1:** wait-for-start on GPIO0 (rule 9.11) - BENCH TEST PENDING, do not merge to main until verified ([7a0f027](https://github.com/teddriveomo/wro-2026-future-engineers/commit/7a0f027d41a9064f6392d550cbab58e85795a8fb))
* **round2:** controller+vision v2 - LAB-u8 LUT, logging stack, GPIO32 start ([24456fa](https://github.com/teddriveomo/wro-2026-future-engineers/commit/24456fac175d0d0420cd3cc43a8ef2691da5b236))
* **t-photos:** official team photo - three members with the vehicle on the practice mat (2026-08-12) ([85d7dd3](https://github.com/teddriveomo/wro-2026-future-engineers/commit/85d7dd394b16f9c4c98a700aeec1c417df47019d))

### Bug Fixes

* **detector:** correct both-pillar wrong-side figure to the 0.45 sweep value ([d6321dc](https://github.com/teddriveomo/wro-2026-future-engineers/commit/d6321dc135ce470817c412a0e2cf89d919a68460))
* **readme:** repair double-encoded UTF-8 across 32 lines ([01a17f4](https://github.com/teddriveomo/wro-2026-future-engineers/commit/01a17f427518baf90df71f9a93d2d21d4f83b61d))
* **readme:** repair one cp1252 em-dash byte introduced by the previous commit ([ac43beb](https://github.com/teddriveomo/wro-2026-future-engineers/commit/ac43beb5430af920163695af175eb1a09b2404a8))
* **readme:** restore byte-exact UTF-8 from f7aa2cd and re-apply the team-photos row via a safe edit (reverts the encoding damage of the prior two commits) ([e14c2a5](https://github.com/teddriveomo/wro-2026-future-engineers/commit/e14c2a5c2f6348e96144008ea7d07850c8708b1b))
* Round 2 hardening - state-gated protocol, wait-for-start, IMUPLUS, gradient visual steering, headless runtime ([ef19e54](https://github.com/teddriveomo/wro-2026-future-engineers/commit/ef19e54ca83fc8883eaa7a52c4a49d30196a26e6))
* **round1:** correct steering-correction sign; retune servo geometry and drive speed ([58adb1c](https://github.com/teddriveomo/wro-2026-future-engineers/commit/58adb1c7ef969233fe1481b896d4ce1c8d833d88))
* **round1:** start button GPIO0 -&gt; GPIO32 (matches physical wiring) - bench pending ([18d7edb](https://github.com/teddriveomo/wro-2026-future-engineers/commit/18d7edb87499133fd7511dcae2d13127fe23e19a))
* **round2:** align servo center/limits to the mat-tuned linkage; center the servo-angle init ([ef9156a](https://github.com/teddriveomo/wro-2026-future-engineers/commit/ef9156a34e505f5150702939db35998f15d408fe))
* **v-photos:** replace the 2026-08-05 set - it showed the pre-redesign chassis ([2e4ae88](https://github.com/teddriveomo/wro-2026-future-engineers/commit/2e4ae882869aea125e6841a81233585b450282d2))

### Documentation

* **3_software:** Open-Challenge control-law paragraph updated to the 58adb1c tune ([2d0d405](https://github.com/teddriveomo/wro-2026-future-engineers/commit/2d0d405c3a17a700a6fc54cacbc44c55f147b49d))
* add 2026-08-08 test runs; record firmware-revision status per run ([92e21cf](https://github.com/teddriveomo/wro-2026-future-engineers/commit/92e21cfcefdf5fb6488c49891ac49d7b390fcd55))
* add 2026-08-09 drive-speed test runs and failure timeline ([962e367](https://github.com/teddriveomo/wro-2026-future-engineers/commit/962e3676a6a10f42c03119bb71e0e3e54ca12a12))
* add 2026-08-09 Round 1 runs at two inner-wall configurations ([2bf61ad](https://github.com/teddriveomo/wro-2026-future-engineers/commit/2bf61ad6bb245832efc69ba9e8b8b137cbfad845))
* add bench and field imagery - chassis prototype, live detector, camera POV series ([9af68c3](https://github.com/teddriveomo/wro-2026-future-engineers/commit/9af68c37f3d3fcfdb92a3de8e11d179332f3d6f0))
* add criterion-aligned engineering documentation set ([54fde20](https://github.com/teddriveomo/wro-2026-future-engineers/commit/54fde20545bfe847775abca472bef8cf08e4b024))
* add Round 2 development history and 2026-08-05 bench photographs ([3d53168](https://github.com/teddriveomo/wro-2026-future-engineers/commit/3d5316862b89d88786864a9ef74df9ae3192e7b1))
* align repo with field state - picker stack of record, drive chosen ([9f47412](https://github.com/teddriveomo/wro-2026-future-engineers/commit/9f47412d99345ac51b9637b3ebcabc97d5b0afd7))
* as-built hardware facts - N20/pack/wheels/servo specs, power tree, wheel-retention failure ([9aae6af](https://github.com/teddriveomo/wro-2026-future-engineers/commit/9aae6af342b547b74e2a6c8c8e00bc60ee8dfe66))
* chassis rebuild CANCELLED - current chassis is FINAL; R10 rewritten on 08-09 run evidence ([b06519e](https://github.com/teddriveomo/wro-2026-future-engineers/commit/b06519ebb4f0f33cc3874fea74d9aed91dee69ec))
* consistency sweep - one dated truth per fact across the repo ([fab45dc](https://github.com/teddriveomo/wro-2026-future-engineers/commit/fab45dc929450f721e28cf4cccadbc261e07fa69))
* consistency sweep - pinion:crown 20:28 landed everywhere, models/ and video rows current, rebuild-cancelled table row fixed, schemes power tree marked historical (2200 mAh label read), GPIO32 diagram omission documented, t-photos roster final ([88ad4b4](https://github.com/teddriveomo/wro-2026-future-engineers/commit/88ad4b4bba0c84a4879ae5a5010a12c9a658fa89))
* correct video/video.md - build and both controllers are in-repo; demo recordings pending ([ab05d96](https://github.com/teddriveomo/wro-2026-future-engineers/commit/ab05d963e85d607bc0eb9abeb8b3038ec7cc2c95))
* engineering journal DRAFT (five-criteria structure, fill placeholders marked) ([0735662](https://github.com/teddriveomo/wro-2026-future-engineers/commit/0735662f9e5a65c62bcfc3407c501ed5af25d4be))
* **journal:** bring the printed artifact level with the repo ([a1f06dc](https://github.com/teddriveomo/wro-2026-future-engineers/commit/a1f06dcfca0ddb5dd35345b03c4e4aaf6ec5176e))
* **journal:** pre-print truth pass - pack 2200 mAh x3, as-built power topology (servo on Buck-2, ESP32 from Pi USB), roster +Diaan, models/ status current, run-video links filled ([7d8da35](https://github.com/teddriveomo/wro-2026-future-engineers/commit/7d8da35f7b1fb0b8a1a68e996e96633db191e631))
* **journal:** truth pass against the 2026-08-10 tree ([178387e](https://github.com/teddriveomo/wro-2026-future-engineers/commit/178387e834e19815768753e0b4ffb80c87aef083))
* kill two live contradictions found in an A5 sweep ([d3ab8d8](https://github.com/teddriveomo/wro-2026-future-engineers/commit/d3ab8d88ad4bd26e3467c287af9afe49f70e9d2b))
* magenta as a third calibrated class; controller as-committed ([3a4a92e](https://github.com/teddriveomo/wro-2026-future-engineers/commit/3a4a92e7c44799df768111042e6705d96558a780))
* **mobility/D8:** the wheel-shed fix was a LEGO frame redesign, not an unknown ([44c38af](https://github.com/teddriveomo/wro-2026-future-engineers/commit/44c38affe14c2f8b6d5156fef321567c5c669ab6))
* **mobility:** torque, traction and acceleration derivation ([44f6eec](https://github.com/teddriveomo/wro-2026-future-engineers/commit/44f6eec3820880295b806a19bb975d9de2d374bb))
* parking = implement (D7, 1.8.3 economics) and chassis rebuild to 3D-printed (D8) ([4a9b919](https://github.com/teddriveomo/wro-2026-future-engineers/commit/4a9b919dd1d9b9dd4cb017cbcc520012b037c8f1))
* **power:** datasheet-derived predicted budget; measured column empty by design ([929f7b9](https://github.com/teddriveomo/wro-2026-future-engineers/commit/929f7b9e1bce86ba041f689da3c8a9b341a57eaf))
* **power:** first measured entry - pack 12.47-12.49 V in predicted band; bench-conditions footnote; ambiguous 5 V-node reading withheld pending probe-point confirm ([f231a4f](https://github.com/teddriveomo/wro-2026-future-engineers/commit/f231a4f816d7b5fb80365c54079bd5d9c7215a25))
* **power:** per-rail current derivation - the arithmetic chain behind the predicted bands ([638f618](https://github.com/teddriveomo/wro-2026-future-engineers/commit/638f618555f0f59664f58f677e96bd8b8d64aaf1))
* reconcile 3_software with the landed Round 2 stack ([db9ee72](https://github.com/teddriveomo/wro-2026-future-engineers/commit/db9ee72f5e8cb9427d0198e02228111a2930038c))
* reconcile hardware truths read off vehicle 2026-08-11 ([b63d111](https://github.com/teddriveomo/wro-2026-future-engineers/commit/b63d11109a7b24e984d76b77385e7177832fc0fd))
* replace directory placeholders with artifact status and blockers ([23ba9f5](https://github.com/teddriveomo/wro-2026-future-engineers/commit/23ba9f5850d6039234019f74e7b56243e01cc4df))
* repo-wide consistency pass against the 2026-08-10 tree ([5f199fc](https://github.com/teddriveomo/wro-2026-future-engineers/commit/5f199fca482be21c331a1d977e08f93a69a1d207))
* rewrite root README around the five scoring criteria ([77de22c](https://github.com/teddriveomo/wro-2026-future-engineers/commit/77de22c8069f6d3287481d8770c32db7223557e1))
* **schemes:** add signal-wiring schematic v0.1 (PNG + PDF) ([74c40fd](https://github.com/teddriveomo/wro-2026-future-engineers/commit/74c40fd8faf8528d53732932170cb53eca5e5ae2))
* **schemes:** pin-verified full-system circuit diagram (6/6 vs firmware) ([675fb16](https://github.com/teddriveomo/wro-2026-future-engineers/commit/675fb16b51b83e587fa67224c7e6f89b9b917f04))
* **schemes:** wiring v0.2 - power tree drawn; TBDs and missing switch/fuse on-sheet; generator committed ([c8ff12b](https://github.com/teddriveomo/wro-2026-future-engineers/commit/c8ff12b13a906fd176ef74030b029a958707419c))
* **software:** section 7 - testing and tuning process ([a60ab4f](https://github.com/teddriveomo/wro-2026-future-engineers/commit/a60ab4f8f9739aba5772c4003d258a7f6e8716c1))
* start button + power switch are rule-mandated (9.6/9.10/9.11); impact-path facts ([15523ce](https://github.com/teddriveomo/wro-2026-future-engineers/commit/15523cee70e8656b6eb436f6ab142969420dbcd1))
* **t-photos:** status current - official photo committed 2026-08-12, informal outstanding ([2af5229](https://github.com/teddriveomo/wro-2026-future-engineers/commit/2af52290694f88b049d1de3c85141f38ab4da45a))
* vehicle built to Round-1 configuration - six-view v-photos, differential drive documented ([727e785](https://github.com/teddriveomo/wro-2026-future-engineers/commit/727e785a9ca5fe3d8d08ec983170f4d1a10c297d))
* **video:** YouTube demo links for both challenges - Open 33 s / Obstacle 100 s, unlisted per Ch.7 - plus build attribution ([c9b0335](https://github.com/teddriveomo/wro-2026-future-engineers/commit/c9b0335ef725168feec470475751e8be92682c0f))

## [0.2.0](https://github.com/teddriveomo/wro-2026-future-engineers/releases/tag/v0.2.0) (2026-08-05)

*Cut by hand this once: the release workflow is blocked until repository
settings allow Actions to create pull requests. Content matches what
`release-please` would have generated from the commits.*

### Features

* **round1:** land canonical N20/TB6612 drive integration (406e315)

### Bug Fixes

* **detector:** correct both-pillar wrong-side figure to the 0.45 sweep value (d6321dc)

### Documentation

* **schemes:** add signal-wiring schematic v0.1, PNG + PDF (74c40fd)
* align repo with field state — picker stack of record, drive chosen (9f47412)
* add bench and field imagery — chassis prototype, live detector, camera POV series (9af68c3)
* vehicle built to Round-1 configuration — six-view v-photos, differential drive documented (727e785)

## Before v0.1.0

The project predates this changelog. The narrative history, including the
problems each stage exposed, is in the version-history table in
[`README.md`](README.md#version-history) and the full reasoning is in
[`docs/4_systems_and_decisions.md`](docs/4_systems_and_decisions.md).

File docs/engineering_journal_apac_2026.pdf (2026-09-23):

T EAM T E D DRIVE | WRO FUTURE ENGINE ERS 2 0 2 6 | ENGINE ERING JOURNAL

WRO FUTURE ENGINEERS 2026 · APAC

# Engineering Journal

## Team TED Drive · WRO Future Engineers APAC 2026

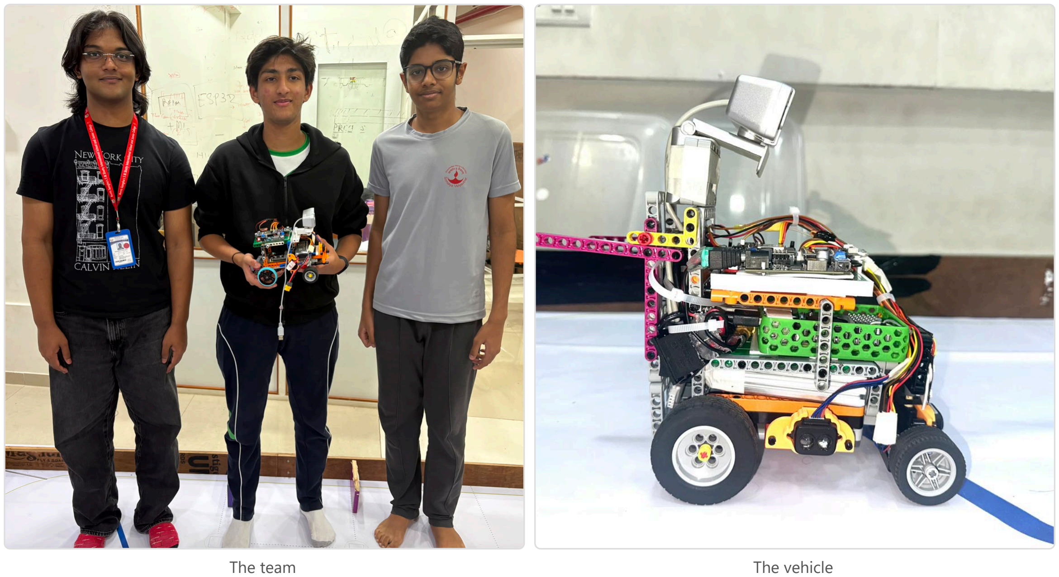
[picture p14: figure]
The team; The vehicle

Team | Ethan Fernandes (software) · Tejas Sirikonda (mechanical) · Deeyan Mehta (electronics)
Coach | Amey Chavan (OMOTEC)
Competition | WRO Future Engineers 2026, APAC, Hyderabad, September 2026
Repository | github.com/teddriveomo/wro-2026-future-engineers
Structure | WRO 2026 General Rules, Appendix C: sections 02 to 06 follow its five criteria

The repository holds the code, the measurements, the car's run logs and the documents this journal is built from, so the two always say the same thing.

T EAM T E D DRIVE | WRO FUTURE ENGINE ERS 2 0 2 6 | ENGINE ERING JOURNAL

## 01 Snapshot

The APAC vehicle in one page; every figure is from this journal and the repository.

Vehicle | An 84-step LEGO Technic frame (332 g bare), a steering column that turns the whole front axle 60° each way, the camera on a 24.8 cm tower pointing 12° down, six WS2812 LEDs on the front frame.
Mass | 862 g race-ready with the Raspberry Pi 5 (measured 16 September).
Drive | MEX 6 V motor through a TB6612FNG driver to the rear wheels: 422 rpm free-running at the wheel and 0.89 m/s average over 3 m from a standing start (measured 21 September).
Power | 3S 2200 mAh pack: 1.34 A idle, 1.93-2.02 A driving, 2.77 A worst case (each branch measured, 21 September).
Compute | Raspberry Pi 5 (camera, detection, decisions) and ESP32 (drive motor, servo, three TF-Luna, LEDs), linked by USB serial.
Software | main.py : Lab-colour pillar detection with tape-line and black-wall corner cues, a state machine that recentres between the walls after every pillar and corner and steers off a side wall during pillar passes, two pillars per straight, and a hand-over to a parking module after the twelfth corner (§04).
Open Challenge | open-challenge.ino on the ESP32 alone: direction detection, wall following at 30 cm with heading hold, twelve 90° turns on the BNO055 heading, and a stop 150 cm from the wall ahead (§04).
Evidence | The car's own logs: 27 runs from the parking lot reached the twelfth corner, the fastest in 154 s; parallel_parking.py parked in 15 of 32 attempts (§07). Bench measurements of drive, power and camera geometry (§02, §03); detection shown on the mat (§04); code stored byte-for-byte with MD5 checksums (§06).

### Contents

§ | Section | Appendix C
01 | Snapshot
02 | Mobility: frame, drive, steering, camera placement, six views | C1
03 | Power and sensing: LEDs, measured power budget, failure points, ESP32 pins | C2
04 | Software and obstacle strategy: control loop, states, recovery, detection, parking, validation | C3
05 | Engineering decisions: every change with its reason, evidence and cost | C4
06 | Reproducibility: files, serial link, settings, provenance and checksums | C5
07 | Validation: the car's run logs, 15-22 September | C3, C4

TED Drive · WRO FE 2026 Engineering Journal, · 2 / 26

T EAM T E D DRIVE | WRO FUTURE ENGINE ERS 2 0 2 6 | ENGINE ERING JOURNAL

## 02 Mobility

How the car is built and moves (Appendix C, criterion 1).

Scope. The vehicle that competes at WRO Future Engineers APAC 2026, built after the India National Championship (26–28 Aug 2026): what changed and why. Every figure is marked by its basis: measured on the vehicle, team figure not yet measured, derived by calculation from named inputs, or vendor specification. Documents 1–5 remain the record of the Nationals configuration.

### 1. Specification

| Nationals (Aug 2026) | APAC 2026 (Sep 2026) | Basis
Length × width × height | length 23.0 cm | 19.1 × 14.3 × 27.2 cm (±0.5 cm) | measured
Mass | 785 g | 862 g race-ready, Raspberry Pi 5 included (measured 2026-09-16) | measured
Axle loads | — | front 201 g, rear 661 g (23 % / 77 %) — see §2 | measured
Chassis | LEGO Technic space-frame, 69-step build | LEGO Technic frame, 84-step build (instructions); (https://github.com/teddriveomo/wro-2026-future-engineers/blob/main/models/chassis/chassis_build_instructions_apac_2026-09.pdf) 332 g bare | build file; measured
Printed parts | TF-Luna holders, servo horn beam, motor clamp ( models/ (https://github.com/teddriveomo/wro-2026-future-engineers/blob/main/models) ) | the same STL files | team
Steering | single-servo Ackermann (MG90S) | non-Ackermann: an MG90 servo drives a vertical steering column that turns the front axle, 60° each side | team
Wheelbase | — | 13 cm | team
Wheels | front 41 mm, rear 55.6 mm | front 45 mm, rear 55 mm (rear tyres chosen for grip) | team
Drive motor | N20 gearmotor, 12 V, 600 rpm, via TB6612FNG | MEX motor (Avishkaar), rated 6 V, 400 rpm, via TB6612FNG — see §3 | team
Gearing | 20T pinion → 28T crown on a LEGO differential (5:7) | unchanged | team
Battery | 3S LiPo, 11.1 V, 2200 mAh | unchanged | team
Power | pack → fast-charge module → Pi 5; pack → Buck-2 → 5 V rail (TF-Lunas, servo); TB6612FNG from the pack (2 — Power & Sensors) (https://github.com/teddriveomo/wro-2026-future-engineers/blob/main/docs/2_power_and_sensors.md) | unchanged, plus the WS2812 LEDs on the 5 V rail; power switch on the battery lead; start button on the rear beams | team
Sensors | 3 × TF-Luna on a PCA9548A, BNO055, USB camera on a front arm at ~10 cm | same sensors; the camera (Lenovo 300 FHD) sits on top of a rear tower — see §4 | photos; measured
Lighting | none | 6 × WS2812 LEDs (three 2-LED strips) on the front frame — see §5 | team

Wiring: schemes/wiring_apac_2026.md (https://github.com/teddriveomo/wro-2026-future-engineers/blob/main/schemes/wiring_apac_2026.md) . Photos: v-photos/apac-2026-09-22/ (https://github.com/teddriveomo/wro-2026-future-engineers/blob/main/v-photos/apac-2026-09-22) — six views, 2026-09-22.

### 2. Weight and balance

Quantity | Value | Basis
Total, race-ready | 862 g | measured
Front / rear axle | 201 g / 661 g (23 % / 77 %); the two sum to the total | measured
Centre of mass | 10.0 cm behind the front axle (13 cm × 661 / 862) | derived
Bare chassis | 332 g, split 31 % / 69 % | measured
Everything added to the chassis | 530 g, about 82 % on the rear axle | derived

Assuming the added parts share the chassis's split would have put 67 g too much on the front, which is why the full car was weighed per axle.

The driven rear wheels carry 77 % of the weight, which helps traction. The steered front wheels carry 23 %, on the smaller tyres, so front grip is what limits cornering. Planned check: measure the turning circle at walking pace and at race speed; a much wider circle at speed means the front is sliding.

### 3. Drive

Motor: MEX motor (Avishkaar), rated 6 V and 400 rpm no-load (team).
Speed at the rated voltage: 400 rpm × 20/28 = 286 rpm at the rear wheels; × π × 55 mm = 0.82 m/s no-load (derived).
Voltage the motor sees: the TB6612FNG switches the pack (11.1 V nominal, 12.6 V full) with PWM, so the motor's average voltage is duty × pack voltage. With the Nationals firmware, full commanded speed was 100 % duty (12.47 V measured at the motor terminals) and half speed was 48 % duty (5.95 V) — see 2a. (https://github.com/teddriveomo/wro-2026-future-engineers/blob/main/docs/2_power_predicted_budget.md) On a 6 V motor, duty above about 48 % on a full pack averages more than its rating. The APAC firmware writes the duty directly with an 8-bit analogWrite and no cap: SPEED = 210 is 82 % duty, 9.1 V average on the nominal pack and 10.4 V on a full one, 1.5–1.7 times the motor's 6 V rating (derived). Turning ( 100 , 39 %), parking ( 70 , 27 %) and the collision escape ( 80 , 31 %) stay under the rating. The motor temperature after a full 3-minute run has not been measured yet.
Measured 2026-09-21 (pack at 12.3 V, SPEED = 210 , so 10.1 V average; ammeter in the motor wire unless stated):
Test | Result | Basis
Rear wheels lifted, free-running | 0.33 A; rear wheel 422 rpm (slow-motion video of a taped wheel, counted over one minute) = 1.22 m/s | measured
Driving on the mat | 0.599 A | measured
Wheels held (stall), ammeter on the battery lead | 1.24 A, which is 1.51 A through the motor at 82 % duty | measured; motor figure derived
3 m straight line from a standing start | 3.36 s, 0.89 m/s on average with the launch included | measured

Speed check. Scaling the rated 400 rpm linearly to 10.1 V predicts 482 rpm at the rear wheel. The measured 422 rpm is 12.5 % lower, because linear scaling ignores the voltage lost in the winding and the drivetrain friction that shows up as the 0.33 A free-running current.
Motor model (derived). Treating the motor as a standard DC motor (voltage = current × resistance + speed × motor constant) and fitting it to the free-running and stall points gives 6.71 Ω including the driver and 0.128 V·s/rad at the gearmotor output. At the measured 0.599 A on the mat it predicts 0.94 m/s, and 3.37 s for the 3 m standing start (launch time constant 0.17 s). The measured time is 3.36 s.
Torque and grip (derived; drivetrain efficiency beyond the free-running losses assumed 0.8). The rear axle gets about 0.04 N·m while cruising (1.4 N at the tyres, the rolling and drivetrain load on the mat) and 0.17 N·m at stall (6.2 N at the tyres). The rear tyres carry 6.5 N (661 g), so 6.2 N would need a friction coefficient of 0.95: a hard launch or a push against a wall spins the rear wheels on most surfaces before the motor stalls.

### 4. Camera placement

Mount: lens centre 24.8 ± 0.5 cm above the floor; optical axis 12° below horizontal (78° from straight down); the hinge is glued at that angle (measured).
Field of view: Lenovo lists a 95° diagonal field of view (product page), (https://store.lenovo.com/in/en/lenovo-300-fhd-webcam-gxc1b34793-387.html) which is about 56° vertical and 87° horizontal at 16:9 (derived; not measured on this camera).
Quantity | Formula | Value
Where the optical axis meets the floor | h / tan α | 117 cm ahead of the lens; about ±10 cm per 1° of angle error
Nearest floor in view | h / tan(α + VFOV/2) | ~29 cm from the lens; the lens sits ~10 cm behind the front wheels, so ~19 cm ahead of them
Separation of pillar bases at 0.5 m and 1.0 m | atan(h / 0.5 m) − atan(h / 1.0 m) | 12.5° (5.6° with the Nationals 10 cm mount)

Quantity | Formula | Value
Tops of walls 1–3 m away | α − atan((h − 10 cm) / D) | 3.6°–9.2° above the image centre

h = lens height, α = pitch below horizontal, VFOV = vertical field of view, D = distance to the wall.

Why the camera went up. Reading range from the image depends on how low a pillar's base sits (the Nationals rule, 2 — Power & Sensors §3). (https://github.com/teddriveomo/wro-2026-future-engineers/blob/main/docs/2_power_and_sensors.md) Raising the lens from ~10 cm to 24.8 cm makes that signal about 2.2 times stronger (12.5° against 5.6° between pillars at 0.5 m and 1.0 m), and the centre of the image lands ~1.2 m ahead instead of 0.33–0.57
m. The separation keeps growing with height up to h = √(Z_near · Z_far), 55 cm for pillars at 0.3 m and 1.0 m, so the earlier statement in §3 of that document, that a higher mount compresses it, was wrong; it is corrected there.

What it costs.

1. A blind zone: a pillar within ~19 cm of the front wheels has its base below the frame, so the nearest-pillar rule needs a tie-break for boxes cut off at the bottom edge.
2. A view over the 100 mm walls: off-field objects can appear between the wall tops and the horizon, so the pillar search has to stay below the black wall band, not a fixed image row.

Planned checks: a tape on the floor slid until it just enters the bottom of the image (measures the blind zone directly); a start-position reference frame compared before each round (the hinge is glued, but this catches knocks).

### Colour calibration

The colour thresholds are set on the competition mat during one practice round at each venue, under that venue's lighting (team). Two tools in src/apac-2026/tools/ (https://github.com/teddriveomo/wro-2026-future-engineers/blob/main/src/apac-2026/tools) apply the same image processing as main.py : a contrast and brightness scale, a gamma curve, then contrast-limited histogram equalisation (CLAHE, clip limit 2.0, 8 × 8 tiles) on the lightness channel.

1. Image. camera-settings.py shows the live camera image with brightness, contrast and gamma sliders. The values chosen go into BRIGHTNESS , CONTRAST and GAMMA in main.py (committed: 0, 3.0 and 0.7).
2. Colours. lab-calibration.py converts the processed image to Lab and shows a mask while the lower and upper L, a and b sliders move. For each colour the sliders are set until only that colour shows in the mask, and the six values go into COLOR_RANGES in main.py .

Lab keeps lightness (L) apart from the two colour axes, so red (high a) and green (low a) can be separated with L left fully open, and a brighter or dimmer hall mostly changes L. The committed ranges do this: red is a ≥ 184 and b ≥ 108, green is a ≤ 101, both with L from 0 to 255. The blue and orange tape lines are found with fixed HSV ranges
( COURSE_LINE_HSV_RANGES in main.py ), not with these tools.

### The six views

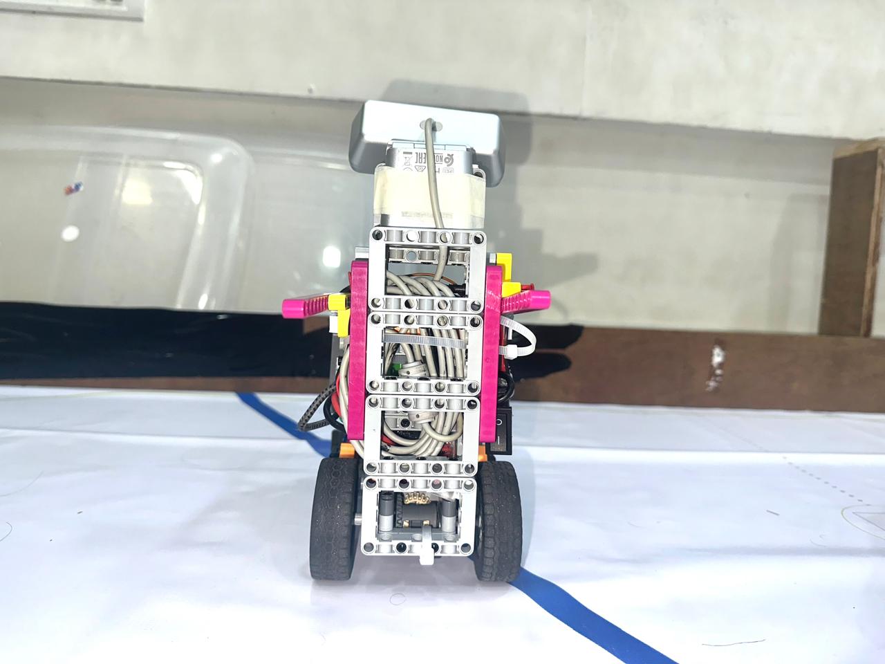
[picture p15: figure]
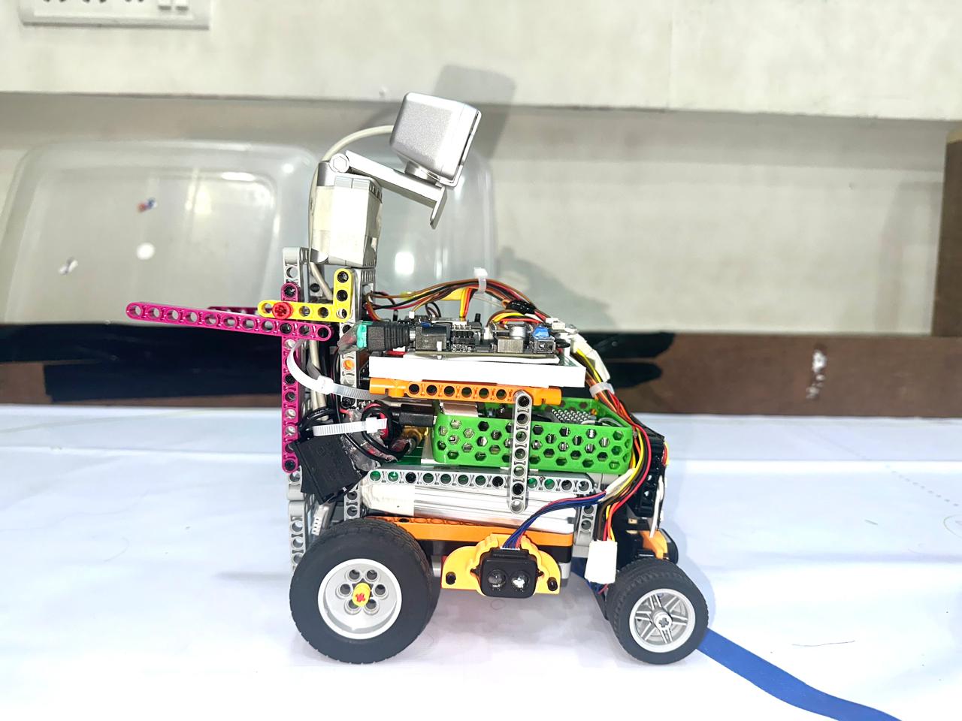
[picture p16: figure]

Front | Rear | Left

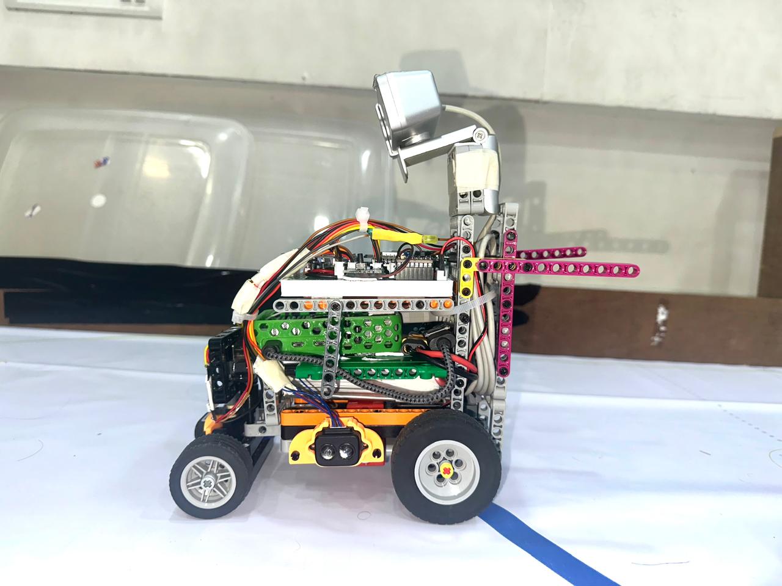
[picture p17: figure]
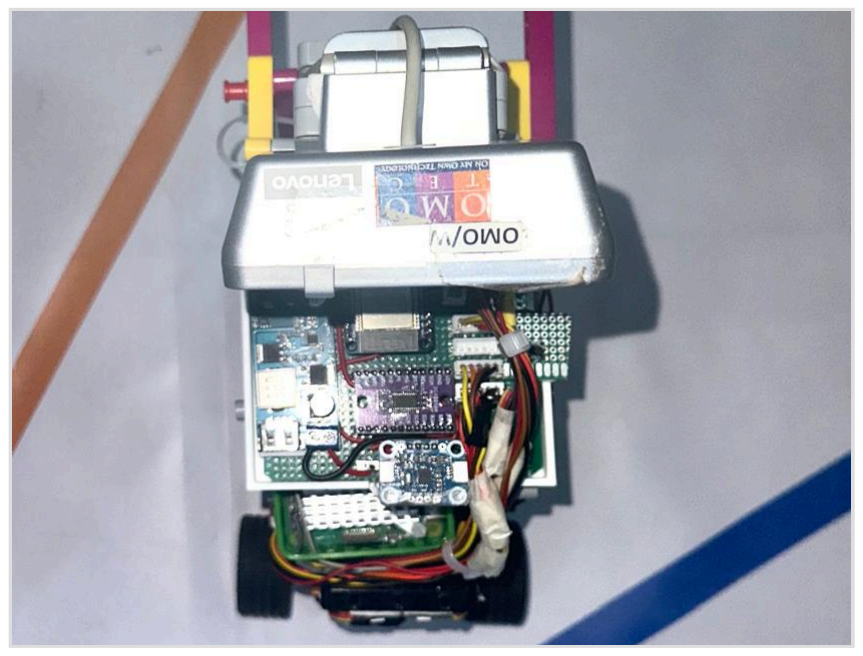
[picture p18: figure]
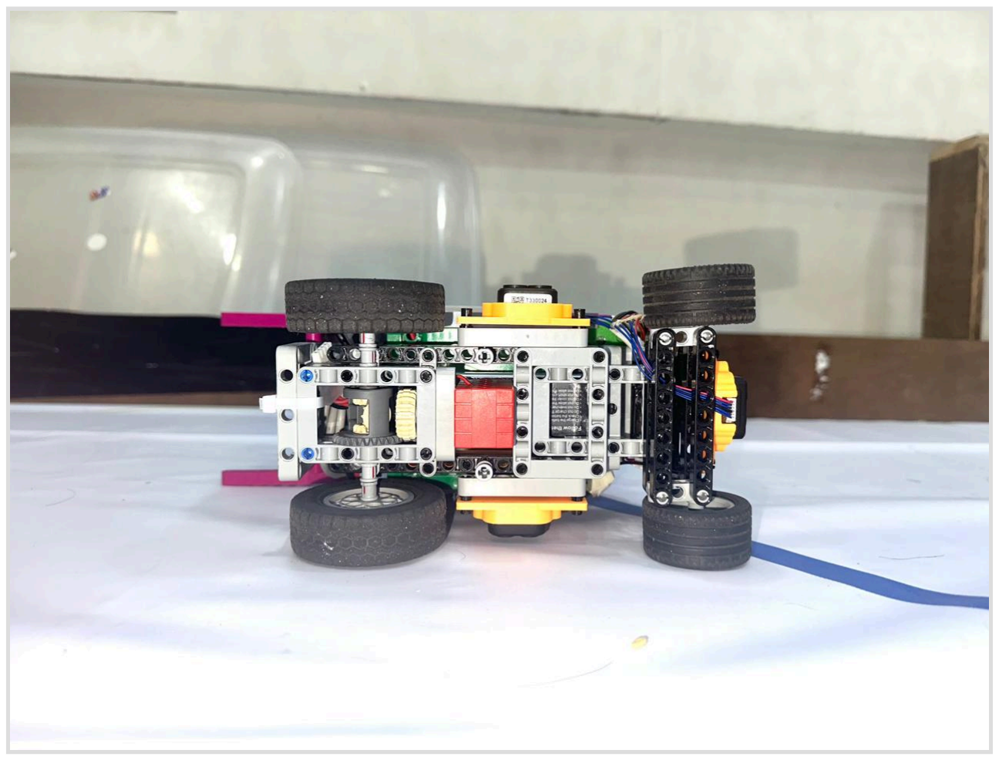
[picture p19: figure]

Right | Top | Bottom (laid on its side)

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

## 03 Power and sensing

What powers the car, what it senses with, and what can fail (criterion 2).

### 5. Lighting and power additions

LEDs: 6 × WS2812 on the front frame; data from ESP32 GPIO4; power from the 5 V Buck-2 rail (team). The firmware lights them white at setBrightness(80) , about 31 % (the bench measurements were taken at 50, about 20 %): roughly 19 mA per LED and 0.11 A for all six by the 60 mA-per-LED full-white rule of thumb in the Adafruit NeoPixel Überguide (https://learn.adafruit.com/adafruit-neopixel-uberguide) (derived). Full white would be 0.36 A.
Switch and button: one power switch on the battery lead; the start button on the rear beams (team). The rules require exactly one power switch and one start button (2 — Power & Sensors §6). (https://github.com/teddriveomo/wro-2026-future-engineers/blob/main/docs/2_power_and_sensors.md)

### Power budget, measured 2026-09-21

Each branch was measured on its own lead from the pack (ammeter and voltmeter, pack at 12.3 V). Pack currents for the two 5 V converters are given at the nominal 11.1 V, the conservative case used in 2a, (https://github.com/teddriveomo/wro-2026-future-engineers/blob/main/docs/2_power_predicted_budget.md) with the converters assumed 88 % efficient; the motor branch is as measured.

Branch | Feeds | Basis | Idle | Driving | Worst case
Buck-2 (5 V) | 3 TF-Luna, servo, 6 LEDs | measured at its input | 0.13 A | 0.23–0.32 A (servo sweeping) | 0.32 A
Fast-charge module (5 V) | Pi 5, camera, ESP32 | measured peak, 11.8 W at the Pi | 1.21 A | 1.21 A | 1.21 A
TB6612FNG | drive motor | measured | 0 | 0.49 A (0.599 A × 82 % duty) | 1.24 A (stall)
Pack total | | | 1.34 A | 1.93–2.02 A | 2.77 A

With the Pi's peak treated as its average, a 2200 mAh pack used to 80 % gives about 52 minutes of driving, about 17 three-minute runs (derived). The prediction for the Nationals car in 2a (https://github.com/teddriveomo/wro-2026-future-engineers/blob/main/docs/2_power_predicted_budget.md) was 0.95–1.40 A driving; the difference is the Pi (an 11.8 W peak against 6.2–8.5 W predicted as an average) and the larger motor.

Part | Load | Rating (vendor) | Use
TB6612FNG, one channel | 1.51 A through the bridge at stall; 0.60 A driving | 1.2 A continuous, 3.2 A peak | 126 % at stall; 50 % driving
Pi 5 USB ports without USB-PD | camera + ESP32 | 600 mA in total | see §6
Battery, 3S 2200 mAh 60C | 2.77 A worst case | 132 A | 2 %

### 6. New failure points

Risk | Effect | Check or mitigation
Pi 5 fed from a USB-A fast-charge module (no USB-PD) | The Pi peaked at 11.8 W (2.36 A at 5 V, measured) and the module's rating has not been read; without USB-PD the Pi limits its USB ports to 600 mA in total, and the camera and the ESP32 both draw from them | Run vcgencmd get_throttled after a full run; move to a 5 A USB-C PD supply if it reports problems
WS2812 data at the ESP32's 3.3 V | The LED input-high threshold is 0.7 × VDD (3.5 V at 5 V); a marginal signal can flicker or show the wrong colour, tinting the scene | Watch for flicker in the camera image; add a level shifter if seen
6 V motor on the 11.1 V pack | Heat and brush wear: SPEED = 215 averages 9.4– 10.6 V, above the 6 V rating (§3) | Temperature check after a 3-minute run

Risk | Effect | Check or mitigation
Drive motor held against a wall | 1.51 A through the TB6612FNG at stall, above its 1.2 A continuous rating (§5); the driver's thermal shutdown or the motor's heating would stop the car | The Pi's distance logic backs away (escape at 31 % duty for 0.30 s, at least 3 cm of progress, at most 2 attempts); on most surfaces the rear wheels spin before a full stall (§3)
Firmware front stop: the ESP32 stopped the drive motor when the front TF-Luna read under 18 cm or its reading went stale | Observed: it stopped the car and ended a run (team) | Removed from the firmware on 2026-09-10; collision handling moved to the Pi (§7)
Camera angle | Pixel-based settings shift if the angle moves | Hinge glued; reference frame before each round
Background above the walls | Off-field red or green objects read as pillars | Search only below the wall band
Blind zone ahead of the wheels | The nearest-pillar rule ties for boxes cut off at the bottom | Tie-break rule in the code

### 8. ESP32 pin map

From the Nationals firmware ( round2_ino.ino (https://github.com/teddriveomo/wro-2026-future-engineers/blob/main/src/Round%202/round2_ino/round2_ino.ino) ) and the 2026-09-20 wiring draft; only GPIO4 is new. Checked against the APAC firmware ( src/apac-2026/ (https://github.com/teddriveomo/wro-2026-future-engineers/blob/main/src/apac-2026) ) on 2026-09-21: it reads the centre TF-Luna on mux channel 3 (channel 1 at Nationals).

Signal | GPIO
I²C SDA / SCL — PCA9548A at 0x70 : ch0 left, ch3 centre, ch2 right TF-Luna ( 0x10 ), ch4 BNO055 ( 0x28 ) | 21 / 22
Steering servo | 13
TB6612FNG AIN1 / AIN2 / PWMA / STBY | 25 / 26 / 33 / 27
WS2812 data | 4
Start button | 32

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

## 04 Software and obstacle strategy

How main.py drives the Obstacle Challenge and how the car parks (criterion 3).

Scope. How the Obstacle Challenge code in | main.py (https://github.com/teddriveomo/wro-2026-future-engineers/blob/main/src/apac-2026/obstacle-challenge/main.py) | works: the control loop and the run (§1–§6), validation (§7), the
parking modules (§8), pillar and line detection (§9), staying off the walls (§10) and the Open Challenge firmware (§11).
Names in capitals are states; names in | code | are constants, given with their values.

### 1. The control loop

In a loop that sleeps 10 ms between passes ( NAVIGATION_LOOP_SECONDS ), the Raspberry Pi:

1. reads the newest ESP32 telemetry line: heading, the left, centre and right TF-Luna distances, and a validity mask;
2. takes the newest camera frame, masks its sides and runs the pillar and tape-line detector
( UnifiedPillarDetector , §9);
3. calls the controller ( ObstacleChallengeController.update ), which sends one | speed,direction,steer | command
to the ESP32.
The run starts once the start button has been held for 2 s: the ESP32 then sends | OK | and the Pi answers | OK . The car
leaves the parking lot ( ENABLE_PARKING_EXIT = True ), drives three laps and, after the twelfth corner ( COUNTER_MAX = 12 ),
hands over to a parking module (PARKING_PARALLEL_HANDOFF, §8). Every state change is printed as | [NAV] OLD ->
NEW: reason , and logged when | ENABLE_RUN_CSV_LOGGING = True | (§7).

### 2. The run

The diagrams in this section and in §3 show the transitions the car took in its logged runs of 19–22 September (89 runs, §7); the labels paraphrase the reasons the code prints.

Leaving the parking lot.

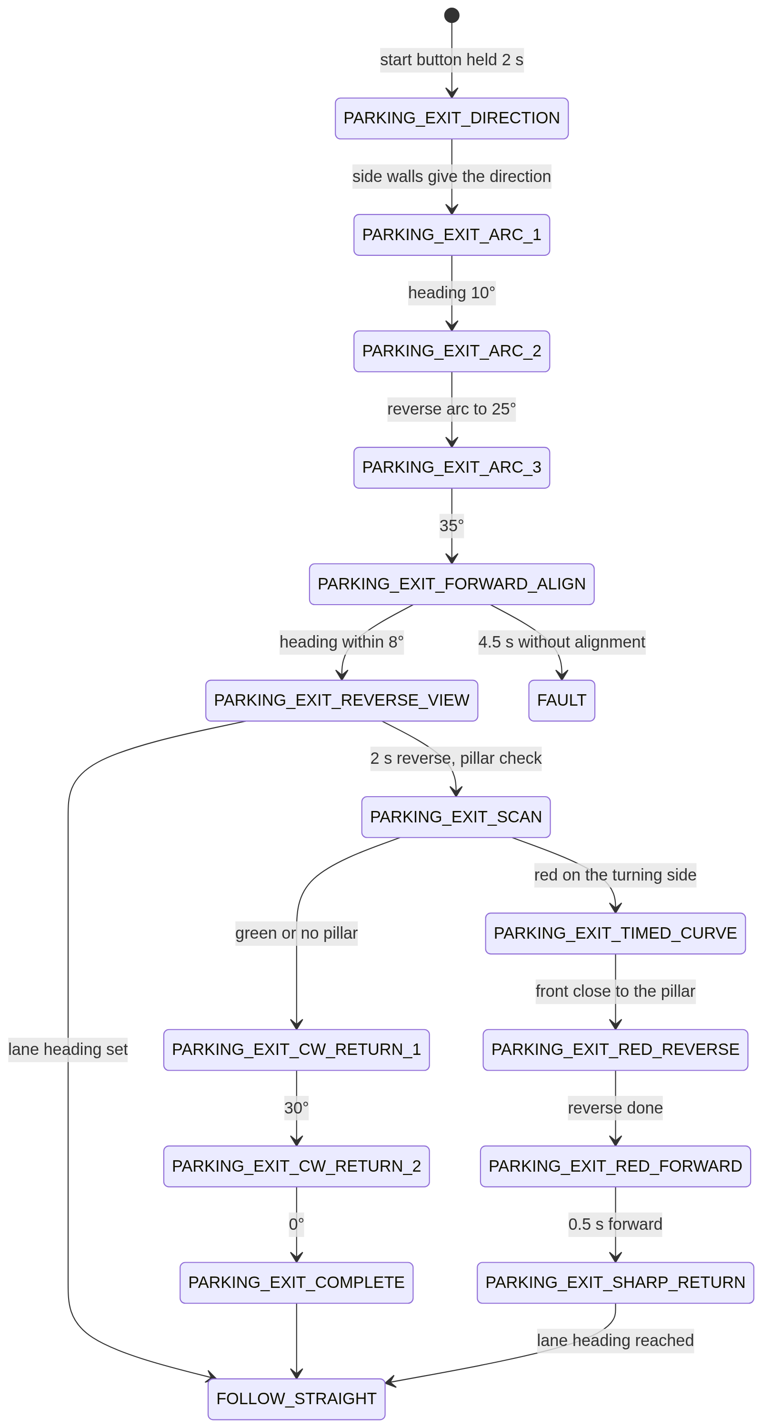
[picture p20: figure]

An anticlockwise start mirrors the lane return (PARKING_EXIT_ANTI_RETURN_1 and _2).

Three laps.

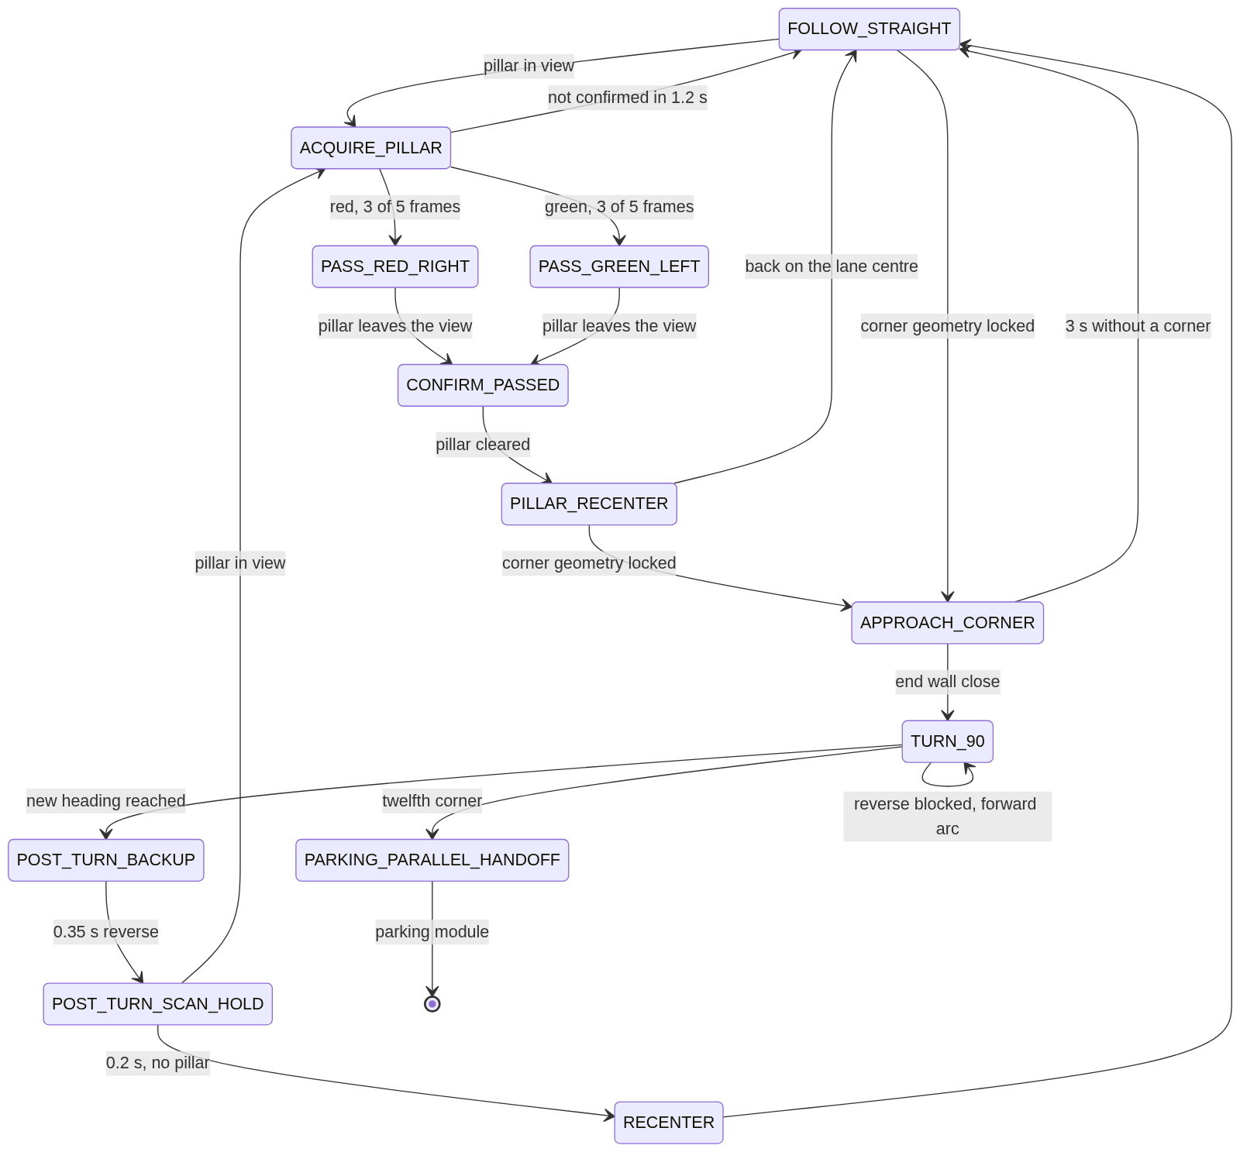
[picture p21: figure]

Red pillars are passed on the right and green ones on the left. If the pillar is still in view after CONFIRM_PASSED, the car returns to its pass state.
At most two pillars are taken on each straight ( MAX_PILLARS_PER_STRAIGHT = 2 ); a pillar seen beyond both tape lines within 5 s of a pass ( ALPHA_POSITION_WINDOW_SECONDS ) belongs to the next straight, so the corner is taken first.
Every driving state brakes and holds while the telemetry is older than 0.30 s ( TELEMETRY_STALE_SECONDS ), a TF-Luna or the heading is invalid, or the camera frame is older than 0.30 s ( CAMERA_STALE_SECONDS ). It resumes in the same state, and the hold does not count against that state's timers.

### 3. Recovery and faults

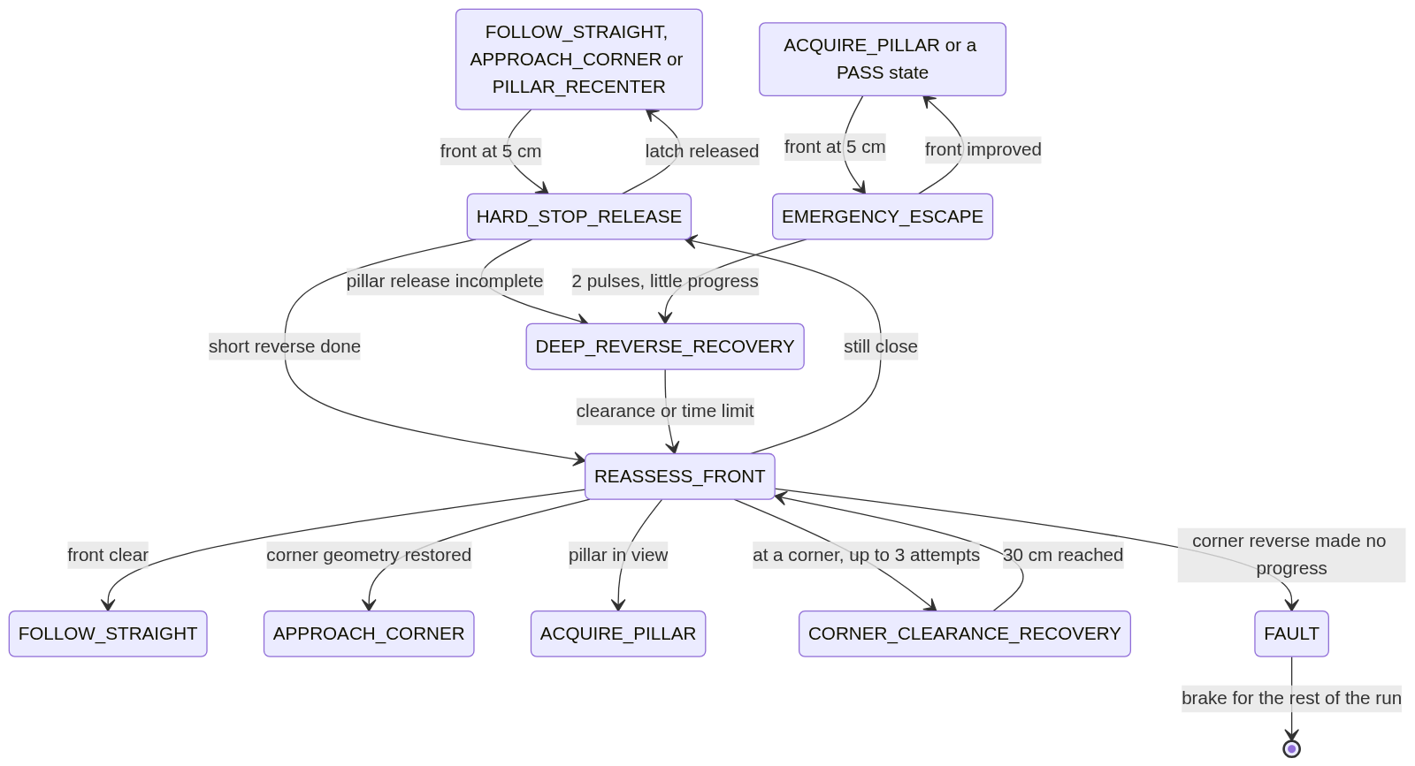
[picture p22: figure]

EMERGENCY_ESCAPE reverses for 0.3 s at speed 80 and resumes the state it interrupted once the front has improved by at least 3 cm ( EMERGENCY_ESCAPE_* ); after 2 pulses without that progress, DEEP_REVERSE_RECOVERY reverses at speed 75 for 0.6 to 0.8 s, aiming for 70 cm of clearance ( DEEP_RECOVERY_* ). HARD_STOP_RELEASE backs off until the
front reads 30 cm ( HARD_STOP_RELEASE_CM ).

The code prints a reason with every FAULT: the turn could not reach its target after retries; the ESP32 did not report an applied reverse; the corner-clearance reverse made no reliable progress; both side walls were too close for a corner reverse; in the parking exit, the forward heading alignment timed out (4.5 s), the red approach took more than 4 s, or the timed return did not reach its heading within 5 s.

### 4. Why the states are split this way

State | Reason
PARKING_EXIT_DIRECTION | The lane direction must be known before the first corner. The code takes it from which side wall is nearer: 7 of the last 9 readings must agree, each with left and right at least 15 cm apart ( DIRECTION_MIN_DIFFERENCE_CM ).
PARKING_EXIT_ARC_1 to _3 | Three heading arcs, the middle one in reverse, turn the car out of the lot to 35° without touching the parking-lot limitations.
PARKING_EXIT_FORWARD_ALIGN, PARKING_EXIT_REVERSE_VIEW | The car straightens to within 8° (at most 4.5 s), then reverses with the camera watching the start section, so the first pillar is seen before the car commits to a side.
PARKING_EXIT_SCAN | A pillar may stand just outside the parking lot. If it is on the side the car turns toward (red when driving clockwise, green anticlockwise), a timed pass keeps the car on its correct side; otherwise two heading arcs return the car to its lane.
ACQUIRE_PILLAR | One frame of red or green must not steer the car, so a pillar is followed only once 3 of 5 frames confirm it; an unconfirmed candidate is dropped after 1.2 s ( PILLAR_ACQUIRE_TIMEOUT_SECONDS ).
CONFIRM_PASSED | The camera loses a pillar before the rear of the car has cleared it, so the car holds its line for 0.25 s ( PILLAR_CLEARANCE_HOLD_SECONDS ).
PILLAR_RECENTER | A pass leaves the car angled towards a wall. A timed counter-steer alone would not prove the drift was cancelled, so the car counter-steers until its heading swings back past straight, then centres between the walls (§10).

State | Reason
APPROACH_CORNER | Neither a tape line nor a short front distance alone proves a corner. The approach locks after three fresh front readings of 105 cm or less; the turn needs the end wall within 35 cm ( OBSTACLE_CORNER_TRIGGER_CM ), the side the car turns toward open to at least 150 cm and the heading within 12° of the straight, in 3 agreeing samples over 0.25 s. After 3 s without a corner the car resumes the straight.
TURN_90 | The target is the straight's heading plus or minus 90°, reached within 5° ( TURN_HEADING_TOLERANCE ). With at least 60 cm of room on the outer side ( CORNER_REVERSE_CLEARANCE_CM ) the turn starts with a reverse arc of up to 0.5 s; if a wall blocks the reverse, the turn continues as a forward arc.
POST_TURN_BACKUP, POST_TURN_SCAN_HOLD | After each corner the car reverses for 0.35 s at speed 125 and stops for 0.2 s, "so several stationary frames can prove a nearby pillar" before the next straight.
CORNER_CLEARANCE_RECOVERY | A car pressed against the end wall cannot turn. It reverses (speed 150, at most 0.4 s per attempt, up to 3 attempts) until the front has 30 cm of clearance, then re-checks the corner while stopped.

### 5. Edge cases the code handles

Situation | What happens
Telemetry or camera stale, or a sensor invalid | Brake and hold the current state; resume when fresh.
A third pillar on one straight | Ignored until the corner (live view: CORNER NEXT - NO NEW PILLAR).
Only one pillar on a straight | 3.6 s after it, the second slot is filled and the corner takes priority ( SECOND_PILLAR_SLOT_TIMEOUT_SECONDS ).
Candidate pillar not confirmed | Back to FOLLOW_STRAIGHT after 1.2 s.
Pillar beyond the corner seen right after a pass | The corner is taken first (§2).
A side wall close during a pillar pass | A correction away from it from 18 cm, with fixed critical and emergency steers at 10 and 6 cm (§10).
Front at 5 cm | A short reverse, then a fresh check for a pillar, a corner or a clear front before moving on (§3).
Reverse blocked during a turn | The turn continues as a forward arc.
Both side walls too close for a corner reverse | FAULT (§3).
Twelfth corner | Hand-over to the parking module (§8).

### 6. Known limits

The driving direction is locked at the start and does not change during the run.
The last-resort front trigger ( PYTHON_EMERGENCY_RELEASE_CM = 5 ) is inside the TF-Luna's blind zone: its specified range starts at 0.2 m (vendor). Corners are normally handled from 105 cm, so this trigger only acts after a misjudgement.
The ESP32 always reports hardStop = 0 (vehicle §7), (https://github.com/teddriveomo/wro-2026-future-engineers/blob/main/docs/apac_2026_vehicle.md) so the hard_stop checks in main.py never fire.
FAULT stops the car for the rest of the run.
After the twelfth corner main.py hands over to the parking module its switches select; it stops with an error if both or neither are on (§8).
Both parking modules end the entry when the front TF-Luna reads 5 cm or less ( ENTRY_STOP_FRONT_CM = 5 ), and
partial_parking.py also uses limits of 6, 8 and 15 cm ( REVERSE_BLOCK_SEARCH_SIDE_STOP_CM , REPOSITION_SIDE_CLEARANCE_CM , REPOSITION_FRONT_CLEARANCE_CM ). All are inside the TF-Luna's blind zone.
In parallel_parking.py , FINAL_REVERSE, FINAL_BRAKE and FINAL_FORWARD are defined, but no transition leads into FINAL_REVERSE, so none of the three is reached; PARALLEL_ALIGN ends the parking in COMPLETE. The docstrings of parallel_parking.py say its detector does not use the blocks' colour; the code
( ParkingGeometryDetector.extract ) keeps only magenta pixels.

### 7. Validation

The metrics that exist, and how the next ones are collected.

Run results, 15–22 September (the car's own logs, APAC 2026 test logs): (https://github.com/teddriveomo/wro-2026-future-engineers/blob/main/docs/apac_2026_test_logs.md) 27 runs from the parking lot reached the twelfth corner, 22 of them on 18–20 September in a median of 176 s (fastest 154 s); parallel_parking.py parked in 15 of 32 attempts on 20 September.
Detector, per frame. The live view shows the tracked pillar's confidence, hits out of 5, bottom position and area band (§9); in the two captured frames of 2026-09-12 the track had 5 of 5 hits at confidence 0.92 and 0.86.
APAC bench, 2026-09-21. Drive and power measurements in vehicle §3 and §5: (https://github.com/teddriveomo/wro-2026-future-engineers/blob/main/docs/apac_2026_vehicle.md) free-running and stall currents, 422 rpm at the rear wheel, 0.89 m/s over 3 m from a standing start, the current of each supply branch.
Run logs. main.py can log every run: with ENABLE_RUN_CSV_LOGGING = True (committed as False ) it writes run_logs/round2_run_<date_time>.csv beside itself, one row per telemetry sample and one per event, with lap, corner count, pillars this straight, state, heading and target, the three distances, the command sent and applied, the tracked pillar with its band, and the tape depths. Those files give corners completed, pillars passed, recoveries and faults per run; the 260 runs logged from 15 to 23 September are summarised in APAC 2026 test
logs. (https://github.com/teddriveomo/wro-2026-future-engineers/blob/main/docs/apac_2026_test_logs.md) For parking, parallel_parking.py with ENABLE_RUN_LOGGING = True (committed as False ) writes a CSV and
an annotated video per attempt (§8).

### 8. Parking modules

Two files beside main.py park the car at the end of the run. After the twelfth corner main.py enters PARKING_PARALLEL_HANDOFF and calls the one its switches select ( PARTIAL_PARKING = True and PARALLEL_PARKING = False as committed; exactly one must be on). Each can also run on its own, and each imports main.py for the camera, the serial link, telemetry, the live view and the shutdown. At the hand-over main.py first registers itself as the module main ( sys.modules ), so the parking module reuses the camera, serial port and telemetry already running ("give the standalone parking module the same initialized camera, serial port, telemetry, and safety API"). Constants named in this section are in the parking files.

File | What it does | Start
parallel_ parking.p y (https://github.com/teddriveomo/wro-2026-future-engineers/blob/main/src/apac-2026/obstacle-challenge/parallel_parking.py) | Parallel parking ( BUILD_ID = "slot-guided-entry-v29" ): finds the two parking-lot limitations with the camera, drives into the gap between them and straightens up | python parallel_parking.py --direction clockwise --last-pillar auto
partial_p arking.py (https://github.com/teddriveomo/wro-2026-future-engineers/blob/main/src/apac-2026/obstacle-challenge/partial_parking.py) | Direct entry: the same approach and block search, then a drive into the space on a locked heading ("Standalone 90 degree parking" in its help text) | python partial_parking.py --direction clockwise --last-pillar auto

--direction is clockwise or anticlockwise ; --last-pillar is auto (detect a red or green final pillar), red , green or
none . Both wait for the start signal as main.py does, and end in COMPLETE with the brake held (exit code 0) or in FAULT with a printed reason (exit code 1).

Which one. A full parallel park scores 15 points against 7 for a partial or non-parallel one (2026 General Rules, scoring element 1.8.2), and touching a limitation ends the round (rule 9.24.7). As committed, the switches select
partial_parking.py ; parking parallel means setting PARALLEL_PARKING = True and PARTIAL_PARKING = False . Every
main.py name the parking modules use exists in the committed main.py .

Camera calibration. Both files need parking_camera_calibration.json beside them. It depends on how the camera is mounted; the team's file, made with the September camera mount, is committed beside them. To make a new one: python parallel_parking.py --calibrate shows the camera image, and clicking the four corners of a rectangle on the floor (near-left, near-right, far-right, far-left; 100 × 150 cm unless --calibration-width-cm and --calibration-depth-cm say otherwise) saves the homography from image to floor. If the file is missing, parallel_parking.py starts this calibration itself and exits after saving.

Finding the space ( parallel_parking.py )

1. Colour mask. Pixels that are magenta in both HSV ( MAGENTA_HSV_LOW 135, 65, 45 to MAGENTA_HSV_HIGH 179, 255,
255) and Lab (a ≥ 145, b ≤ 175). The top 28 % of the image is ignored ( ROI_TOP_FRACTION = 0.28 ); one opening and two closings with a 5 × 5 kernel remove specks and fill gaps.
2. Shape. Each contour's rotated rectangle must fit a 200 × 20 × 100 mm limitation seen face-on, edge-on or at an angle: aspect 1.15 to 6, rectangularity at least 0.42, magenta fill at least 0.45, width at most 30 % and height 5.5 to 72 % of the image, lower edge below 55 % of the image height and not cut off by the bottom of the image.
3. Floor position. The midpoint of the rectangle's two lowest corners goes through the calibration homography, which gives the block's position on the floor in cm.
4. Two blocks. A block is confirmed after 3 hits in its last 6 frames ( BOUNDARY_REQUIRED_HITS , BOUNDARY_HISTORY ). Block 1 is the best-scoring rectangle on the parking side of the image. Block 2 must not overlap it, and must be 25 to 120 cm from it on the floor, within 55 cm of it sideways and at least 15 cm farther away.
5. Slot. The slot is the floor midpoint of the two blocks. It is confident when both blocks are confirmed, neither has been missed for more than 2 frames, they are 25 to 120 cm apart and both have a confidence of at least 0.55. Its bearing from the camera steers the car ( SLOT_BEARING_KP = 2.0 ) and is used only within ±30°
( SLOT_MAX_USABLE_BEARING_DEG ).

States ( parallel_parking.py )

State | What the car does | Leaves when
SEARCH_LAST_PILLAR | Looks for the final pillar with main.py 's pillar detector | a pillar is confirmed: PASS_LAST_PILLAR; no pillar and block 1 confirmed: TRACK_OPENING
PASS_LAST_PILLAR | Steers past the final pillar | red path: SEARCH_FIRST_BOUNDARY; green path: GREEN_RETURN_STRAIGHT back to the start heading, GREEN_FORWARD_STRAIGHT for 1.0 s, then SEARCH_FIRST_BOUNDARY
SEARCH_FIRST_BOUNDARY | Drives at speed 50 on the start heading turned 45° towards the parking side (5° after a green-path pillar). If block 1 is not confirmed within 4 s, a short reverse (0.6 s at speed 60, steer 45) and the search restarts; each retry adds 5° of offset (up to 55°), 0.2 s of search time and a longer, sharper reverse (up to 1.0 s, steer 55; the speed stays 60) | block 1 confirmed: TRACK_OPENING
TRACK_OPENING | The same search | block 2 confirmed and the slot confident: ALIGN_VIRTUAL_CUTOUT
ALIGN_VIRTUAL_CUTOUT | Speed 50, steering on the slot bearing (at most 25) | 8 consecutive updates with a usable bearing ( ALIGN_CONFIRM_SAMPLES ): ENTER_SPACE; front TF-Luna at 5 cm or less: PARALLEL_ALIGN
ENTER_SPACE | Speed 70, steering on the slot bearing (at most 12) | front TF-Luna at 5 cm or less: PARALLEL_ALIGN
PARALLEL_ALIGN | Speed 50 at full correction steer (50): reverse strokes of 0.8 s, then forward until the front TF-Luna reads 5 cm | heading within 2° of 0° on 3 consecutive updates: COMPLETE

The red and green paths swap in an anticlockwise run ( pillar_behavior ). After a green-path pillar, each block search ends in FAULT after 15 s ( GREEN_PARKING_SEARCH_MAX_SECONDS ), and the return to the start heading after 10 s.

What partial_parking.py changes

No final pillar. With --last-pillar none , or when no final pillar is confirmed within 3 s, it drives straight for 2 s at speed 80 (NO_PILLAR_STRAIGHT), then searches for block 1 in reverse at speed 50
(REVERSE_BLOCK_SEARCH).
Green path. Clockwise with a green final pillar (anticlockwise with a red one) it steers 45° forward until the centre TF-Luna reads 30 cm, then turns slowly at full lock the other way to a set heading before the block search

(GREEN_CW_TURN_RIGHT, GREEN_CW_TURN_LEFT; mirrored as RED_ACW_TURN_LEFT, RED_ACW_TURN_RIGHT).
Opening check. Where the parallel module would start aligning, it requires a visible opening at least 6.5 % of the image wide ( MIN_VISIBLE_ENTRY_GAP_RATIO ) and a slot at least 20 cm ahead with a valid bearing. A narrower opening gets one repositioning (REPOSITION_AWAY, REPOSITION_FORWARD, REPOSITION_RETURN) before a FAULT.
Entry. It locks the entry heading at the current heading plus the slot bearing (at most ±30°) and drives in at speed 70, the parallel module's ENTRY_SPEED (ENTER_SPACE). Steering is 2.0 × the heading error plus 0.6 × its integral, which builds only once the slot is closer than 40 cm, plus a smoothed term of at most 8 that centres the opening in the image while the slot is 40 cm or more away; at most 24 in total.
Stop. At a front reading of 5 cm or less, or when the front reading is missing or stale, it brakes (FRONT_SENSOR_HOLD): 3 fresh readings at the stop move on to PARALLEL_ALIGN, and 3 fresh clear readings resume the previous state. PARALLEL_ALIGN works as in the parallel module but counts only fresh telemetry.

### Why it is built this way

Reasons as the code's comments give them.

Choice | Reason given in the code
The TF-Luna sensors are not used while searching for or aligning with the blocks | The blocks' geometry comes from the full camera view; distance matters only once the car is in the space
A short camera miss does not brake the car | The brake is not pulsed between camera frames: the selected motion continues until vision recovers, and during alignment the car drives straight and restarts the confirmation
Avoiding the final pillar starts on its first sighting, but the pass needs several frames of confirmation | At driving speed a one-frame delay can put the pillar past the useful steering window; a false detection can steer briefly but cannot latch the pass
The block search holds a heading offset towards the parking side | So that the blocks enter the camera view; an earlier path turned into the parking area before block 1 was confirmed
Reverse strokes in PARALLEL_ALIGN stop after 0.8 s; forward moves stop on the front TF-Luna | So that the car cannot back out of the space
The shape limits are broad | A limitation can be seen edge-on, face-on, at an angle or cut off by the image edge
One magenta contour never updates both blocks, and a sudden inward jump is taken as the next block | Block 1 leaves the image through its left edge in a clockwise run (the right edge anticlockwise), so a new rectangle further in is block 2, never a new sample of block 1
partial_parking.py ignores a pillar cut off by the image edge | Such an object belongs to the next lane, not to the final pillar ahead

### Failure exits

Every FAULT prints its reason and holds the brake.

parallel_parking.py : after a green-path pillar, the return to the start heading takes more than 10 s, or block 1 or block 2 is not found within 15 s.
partial_parking.py : no valid IMU heading when the entry heading is locked; the opening is still narrower than 6.5 % of the image after one repositioning; the slot is not ahead with a valid bearing; something in front while the final pillar is classified, during the no-pillar straight or during the pillar pass; the pillar pass takes more than 4 s; too little side clearance in the reverse search; too little front or side clearance while repositioning; the opening is lost before the car passes it.

### 9. Pillar and line detection

What UnifiedPillarDetector does with each 1280 × 720 frame, and why. Constants are in main.py ; the two figures at the end show the result on the mat.

1. Image preparation. The frame is stretched ( CONTRAST = 3.0 , BRIGHTNESS = 0 ) and gamma-corrected ( GAMMA = 0.7 ), then converted to Lab; CLAHE (clip 2.0, 8 × 8 tiles) evens out the lightness channel. Lab keeps lightness apart from the two colour axes, so red (high a) and green (low a) separate with L left open, and a brighter or darker hall mostly moves L (vehicle §4). (https://github.com/teddriveomo/wro-2026-future-engineers/blob/main/docs/apac_2026_vehicle.md) The venue's thresholds come from one practice round with lab-
calibration.py .
2. Side masks. Before detection a strip at each side of the frame is set to neutral grey (128, outside every Lab range) without moving pixel coordinates ( asymmetric_camera_view ): 16 % of the width on each side on a straight ( CAMERA_SIDE_MASK_FRACTION ). After a corner the two sides are masked separately, depending on the turn
direction ( post_turn_view_fractions , POST_CORNER_VIEW_SIDE_FRACTION = 0.20 ), until the new straight is
established: 1.5 s of forward driving, or 12 s.
3. Colour masks. One Lab range per colour ( COLOR_RANGES , as committed): red a at least 184 and b at least 108; green a at most 101; blue a 153 to 186 and b at most 90; orange a at least 130 and b at least 150; L unconstrained. Each mask is opened once and closed twice with a 3 × 3 kernel, and the top third of the image is cleared ( DETECTOR_ROI_TOP_RATIO ): from the 24.8 cm mount that third lies above the tops of the walls out to about 3 m (vehicle §4), (https://github.com/teddriveomo/wro-2026-future-engineers/blob/main/docs/apac_2026_vehicle.md) so it holds only the hall.
4. Candidate shapes. Each contour is tested by size and shape. Pillars (red, green): area at least 0.045 % of the frame and height at least 2.5 % of the frame height; height to width 0.65 to 8 (a 50 × 50 × 100 mm sign is about twice as tall as wide; the range allows partial views and perspective); rectangularity at least 0.35 and solidity at least 0.60, since a pillar is a solid rectangle and tape edges and reflections are not. Tape lines (blue, orange): area at least 0.03 %, height at least 1 %, height to width 0.2 to 10, rectangularity at least 0.25, solidity at least
0.50. Confidence = 0.20 × area + 0.20 × height + 0.25 × rectangularity + 0.35 × solidity, with area and height capped at 5 × the minimum area and 25 % of the frame height; candidates under 0.45 are dropped
( DETECTOR_MIN_CONFIDENCE ).
5. Tape lines and the corner reference. The mat's blue and orange lines mark the approach to a corner. They are found in HSV (blue hue 95-135, orange hue 3-22) below the top third, with the same morphology; a line must cover 0.025 % of the frame, span 10 % of its width and be at least twice as wide as tall. The lowest line's midheight is its depth; when both colours are visible, the deeper of the two is the corner reference (the magenta line in the live view). The code also confirms a corner from the black walls: in HSV (value at most 70), a broad black end wall with an opening on the turn side, confirmed in 3 of the last 4 frames ( BLACK_CORNER_* ).
6. Which pillar counts. With the corner reference visible (and not suppressed for 3 s after a turn, POST_TURN_TAPE_IGNORE_GRACE_SECONDS ), a pillar whose centre is above the reference, farther away than the tape, is ignored when it is entirely above it or sits in an outer column of the 5 × 5 grid: it stands beyond the corner or in a side lane (IGNORE CORNER in the live view). Two rules keep the car from dropping the obstacle in front of it: the track the controller is already passing keeps priority even when tape moves in front of it (FRONT PRIORITY), and when a larger, lower interior pillar and a smaller outer pillar are both beyond the reference, the interior pillar stays actionable if it is 1.25 × larger ( CORNER_FOREGROUND_AREA_ADVANTAGE ). A small ignored pillar never suppresses a valid foreground pillar.
7. Tracking. One pillar is tracked at a time. A new track starts on the best candidate by 0.55 × bottom + 0.35 × confidence + 0.10 × area: the lowest in the image is the nearest. Each frame the track is matched to a samecolour candidate by centre distance (at most 0.25 of the frame) or overlap (IoU at least 0.05), and its position is smoothed (0.65 new, 0.35 old). A track is confirmed after 3 hits in its last 5 frames ( DETECTOR_CONFIRMATION_HITS ,
DETECTOR_TRACK_HISTORY ); an unconfirmed track is dropped after 2 misses ( DETECTOR_UNCONFIRMED_MISSES ); a
confirmed track stays locked until the controller records the pass, so a brief occlusion cannot switch the target. Confidence is 0.75 × the detection's confidence + 0.25 × hits/5, and decays by 10 % per missed frame.
8. Two pillars per straight. At most two pillars are taken on each straight ( MAX_PILLARS_PER_STRAIGHT = 2 ); once both are passed, no new pillar is taken until the corner (live view: CORNER NEXT - NO NEW PILLAR). If no second pillar has come 3.6 s after the first, slot 2 is filled and the corner takes priority
( SECOND_PILLAR_SLOT_TIMEOUT_SECONDS ). One high track in the next lane is deferred rather than its whole colour suppressed, and right after a turn nearby pillars take priority ( defer_background_candidate ). A wide, low rectangle, at least twice as wide as tall, is treated as a parking-lot limitation, not a pillar; in laps 1 and 2 the car steers gently around it (speed 60, steering 15).
9. Range and control. The pillar's distance band comes from its area: far under 3,200 px×px, near under 7,000, close under 20,000, otherwise too close; the 1280 × 720 breakpoints are kept as ratios of the frame
( PILLAR_AREA_NEAR_RATIO , | PILLAR_AREA_CLOSE_RATIO , | PILLAR_AREA_TOO_CLOSE_RATIO ). Each band selects a speed,

gain and steering limit ( PILLAR_DISTANCE_PROFILES ; far: speed 100, gain 0.70, 3 to 12 of steer; too close: speed 80, gain 1.50, 38 to 52). The controller steers the pillar to a target column, red to 38 % of the width so the car passes on its right and green to 62 % so it passes on its left ( PILLAR_RED_TARGET_X , PILLAR_GREEN_TARGET_X ), with gain 200 ( PILLAR_LATERAL_KP ), at most 40 of correction and smoothing 0.65.

The live view ( annotate ): the cyan line is the top of the search area; the grey grid is the 5 × 5 columns and rows; blue and orange boxes are tape lines; the magenta line is the corner reference; thin boxes are candidates; a magenta box is a pillar ignored as beyond the corner ( IGNORE CORNER Cn , n = grid column); a yellow box marks the pillar being passed ( FRONT PRIORITY ); the tracked pillar's box is yellow once confirmed and cyan before, labelled TRACK id COLOUR conf hits/5 bottom area BAND , with a vertical line at its target column; the text lines give the state, heading and steer, and the three TF-Luna readings in cm. The live view also shows PILLAR SLOTS n/2, CORNER NEXT - NO NEW PILLAR, SLOT 2 TIMEOUT IN n s, BLACK CORNER and VIEW MASK L=n% R=n%.

Two frames from testing on 12 September.

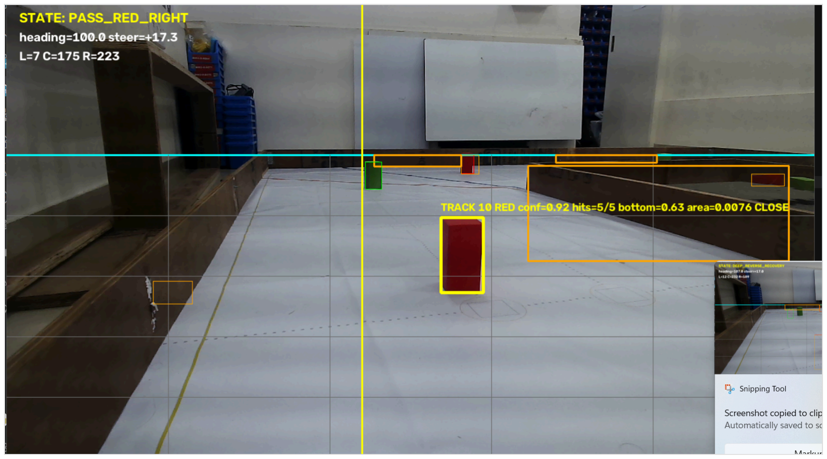
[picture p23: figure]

Passing a red pillar: state PASS_RED_RIGHT, steer +17.3 at heading 100.0; TF-Luna L 7, C 175, R 223 cm; track 18, red, confidence 0.92, 5 of 5 hits, bottom 0.63, area 0.0076, band close; orange tape boxes ahead and the red target column drawn.

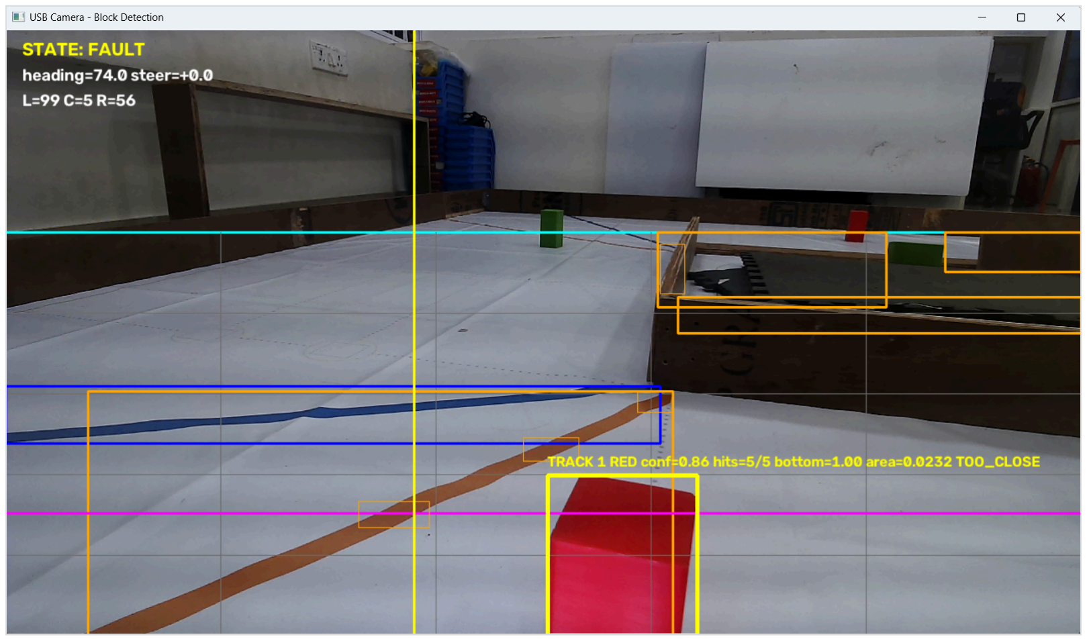
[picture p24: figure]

A run that ended in FAULT: a red pillar 5 cm from the centre TF-Luna (L 99, C 5, R 56 cm), track 1 at confidence 0.86, bottom 1.00, area 0.0232, band too close; both tape lines are visible and the magenta corner reference is drawn. The fault reason is printed to the terminal, not to the view, and was not captured.

### 10. Staying off the walls

Four mechanisms keep the car in the middle of its lane; with them the side rollers were no longer needed (vehicle §7). (https://github.com/teddriveomo/wro-2026-future-engineers/blob/main/docs/apac_2026_vehicle.md)

PILLAR_RECENTER, after every pillar pass, counter-steers 22° against the pass for 0.18 to 0.45 s and moves on once the heading has swung back past straight, "proof it actually cancelled the drift, not just a timer"; it then settles onto the lane centre from the heading and both side TF-Lunas (both walls 8 to 110 cm away, heading within 10°, gain 0.5, at most 18 of steer, 3 confirmations).
A wall guard during pillar passes: a side wall closer than 18 cm ( PILLAR_WALL_WARNING_CM ) adds a correction away from it that grows to 35 at 6 cm; at 10 cm a fixed critical steer takes over, and at 6 cm an emergency steer at speed 65.
Recentering after corners: a side-distance correction ( ROUND2_RECENTER_* : gain 0.45, at most 14, heading within 8°).
CORNER_CLEARANCE_RECOVERY (§4), with the side-clearance check before a corner reverse
( TURN_SIDE_CLEARANCE_CM = 20 ).

### 11. Open Challenge firmware

open-challenge/open-challenge.ino (https://github.com/teddriveomo/wro-2026-future-engineers/blob/main/src/apac-2026/open-challenge/open-challenge.ino) drives the Open Challenge on the ESP32 alone, without the Raspberry Pi or the camera. It uses the same pins, I2C multiplexer channels and sensors as the Obstacle firmware; the servo centre is SERVO_CENTER = 106 here and 85 in the Obstacle firmware. Constants are in the file.

1. Start and direction. After the start button (GPIO32), the car drives at speed 190 ( DETECTION_SPEED ) until one side reading opens beyond 100 cm on 3 samples ( DIRECTION_DETECTION_DISTANCE_CM , DIRECTION_CONFIRMATION_SAMPLES ); that side sets clockwise or anticlockwise, keeping the original priority for the right side.
2. Wall following. At speed 190 ( FOLLOW_SPEED ) the car holds its heading (gains 0.55 and 0.08, | HEADING_KP ,
HEADING_KD ) and keeps 30 cm from the followed wall ( TARGET_LEFT_DISTANCE_CM , | TARGET_RIGHT_DISTANCE_CM ; gain
0.50, at most 12), with at most 25 of steering in total.
3. Corners. When the followed side opens beyond 75 cm on the left or 50 cm on the right on 3 samples, the car turns 90° on the BNO055 heading at speed 160 (gains 0.75 and 0.06, at most 35 of steering) until the error is under 4°. It then drives at speed 210 for a minimum time (500 ms clockwise, none anticlockwise) and reacquires the wall below 50 cm on 3 samples.

4. Finish. After twelve turns ( TOTAL_TURNS ) it holds the heading of the last turn and brakes when the centre TF-Luna reads 150 cm or less ( FINAL_CENTER_DISTANCE_CM ); the electrical brake then stays latched.

The control loop runs every 10 ms ( CONTROL_PERIOD_US ), and servo pulses come from a dedicated task on the other core ( servoPulseTask , 20 ms frames).

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

## 05 Engineering decisions

Each change as a decision: what it replaced, why, the evidence, and the cost (criterion 4).

### 7. Why each change was made

Each change as a decision: what it replaced, the reason the team gives, the evidence in this repository, and what it costs. The largest test-driven change in this vehicle's line is in the Nationals record: the wheel-shed failure of 2026-08-06 led to the space-frame redesign that every later frame descends from (1 - Mobility §3, (https://github.com/teddriveomo/wro-2026-future-engineers/blob/main/docs/1_mobility.md) D8). (https://github.com/teddriveomo/wro-2026-future-engineers/blob/main/docs/4_systems_and_decisions.md)

Change | Instead of | Reason (team) | Evidence here | Trade-off
New 84-step frame, 332 g bare | the Nationals 69-step space-frame | a sturdier structure | build file; the car weighs 862 g against 785 g at Nationals (measured, all changes together) | 77 g more to accelerate and stop; stiffness not measured
Steering column turning the whole front axle, 60° each way | single-servo Ackermann | a smaller turning circle | turning circle not measured | the front wheels no longer follow Ackermann geometry, so they scrub in tight turns
Wheels: front 45 mm, rear 55 mm tyres | front 41 mm, rear 55.6 mm | rear tyres for grip | not measured | none recorded
Camera on a 24.8 cm tower, 12° down | a front arm at about 10 cm | a better view of the track | measured mount, derived geometry: pillar bases at 0.5 m and 1.0 m are 12.5° apart against 5.6° before, a 2.2 × stronger range signal (§4) | a 19 cm blind zone ahead of the wheels and a view over the walls (§4); a taller top, its centre-of-gravity height not measured
Six WS2812 LEDs on the front frame | ambient light | fewer colour mistakes | 0.11 A at the committed brightness of 80 by the rule of thumb (0.07 A at 50, the bench setting); Buck-2 idle 0.13 A measured with them (§5); misread counts not measured | data at 3.3 V may flicker (§6)
Side rollers fitted, then removed | none | fitted to keep the car moving on wall contact; removed once the rewritten wall-avoidance code made them unnecessary, and because they blocked the Raspberry Pi's ports (reported 2026-09-22) | the team ran the car in both configurations without trouble (team); in the logs of 22 September evening, after the removal, 5 of 7 short test runs reached COMPLETE, and the corner-clearance recovery ran in 5 of them (test logs (https://github.com/teddriveomo/wro-2026-future-engineers/blob/main/docs/apac_2026_test_logs.md) §4); the current main.py adds lane recentering after every pillar pass and after corners, a wall guard during pillar passes and a corner-clearance recovery (software §10) (https://github.com/teddriveomo/wro-2026-future-engineers/blob/main/docs/apac_2026_software.md) | without rollers a wall contact stops the car; only the Pi's collision escape (§6) remains
Firmware front stop removed (2026-09-10) | a stop under 18 cm on the front TF-Luna | stopping the drive motor ended a competition run | one run ended (team) | collisions are handled by the Pi's distance logic alone (§6)
Parallel parking at the end ( parallel_p arking.py ) | direct entry ( partial_pa rking.py ) | 15 points for a full parallel park against 7 (2026 rules, scoring element 1.8.2) | rules; logs: 15 of 32 parallel_parking.py attempts parked on 20 September, while the U-turn parking-in of 17 September reached COMPLETE in 0 of 24 (test logs (https://github.com/teddriveomo/wro-2026-future-engineers/blob/main/docs/apac_2026_test_logs.md) §3) | a longer manoeuvre beside the limitations; touching one ends the round (rule 9.24.7)

The front-stop decision. The firmware used to stop the drive motor when the front TF-Luna read under 18 cm (released at 24 cm) or when its reading went stale, and that stop ended a run. On 2026-09-10

forwardHardStopIsActive() | was changed to return | false , with the comment "Disabled: stopping the drive motor here
ends a competition run". Collisions are handled on the Pi: back away at speed 80 for 0.30 s, require at least 3 cm of
progress, at most 2 attempts, release at 30 cm. The same day added a | PARKING_OVERRIDE_ON | serial command to the
firmware; | main.py | never sends it, so it has no effect in a run.

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

## 06 Reproducibility

How to rebuild and run the software exactly as committed (criterion 5).

The code the vehicle runs at WRO Future Engineers APAC 2026: the Obstacle Challenge stack and the Open Challenge firmware. The vehicle is described in docs/apac_2026_vehicle.md (https://github.com/teddriveomo/wro-2026-future-engineers/blob/main/docs/apac_2026_vehicle.md) , and how main.py drives the run, with its state diagrams, in docs/apac_2026_software.md (https://github.com/teddriveomo/wro-2026-future-engineers/blob/main/docs/apac_2026_software.md) . The two parking modules are described in its section 8. (https://github.com/teddriveomo/wro-2026-future-engineers/blob/main/docs/apac_2026_software.md)

File | Runs on | What it does
obstacle-challenge/main.py (https://github.com/teddriveomo/wro-2026-future-engineers/blob/main/src/apac-2026/obstacle-challenge/main.py) | Raspberry Pi 5 | Camera, pillar and line detection, and the driving decisions; sends drive commands to the ESP32
obstacle-challenge/parallel_parkin g.py (https://github.com/teddriveomo/wro-2026-future-engineers/blob/main/src/apac-2026/obstacle-challenge/parallel_parking.py) | Raspberry Pi 5 | Parallel parking at the end of the run ( BUILD_ID = "slot-guided-entry-v29" ): finds the two parking-lot limitations with the camera, drives into the gap and straightens up. Imports main.py ; called by main.py after the twelfth corner when PARALLEL_PARKING = True , or run on its own
obstacle-challenge/partial_parking .py (https://github.com/teddriveomo/wro-2026-future-engineers/blob/main/src/apac-2026/obstacle-challenge/partial_parking.py) | Raspberry Pi 5 | Direct entry into the parking space on a locked heading, reusing the parallel module's approach and block search. Called by main.py after the twelfth corner when PARTIAL_PARKING = True (as committed), or run on its own
obstacle-challenge/esp32/obstacle-challenge-final-code/obstacle-challenge-final-code.ino (https://github.com/teddriveomo/wro-2026-future-engineers/blob/main/src/apac-2026/obstacle-challenge/esp32/obstacle-challenge-final-code/obstacle-challenge-fin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) | ESP32 | Drive motor, steering servo, LEDs, the three TF-Luna sensors and the BNO055 through the PCA9548A; sends telemetry to the Pi
open-challenge/open-challenge.ino (https://github.com/teddriveomo/wro-2026-future-engineers/blob/main/src/apac-2026/open-challenge/open-challenge.ino) | ESP32 | The Open Challenge on the ESP32 alone: direction detection, wall following with heading hold, twelve 90° turns on the BNO055 heading, and a final stop at 150 cm from the wall ahead (software §11) (https://github.com/teddriveomo/wro-2026-future-engineers/blob/main/docs/apac_2026_software.md)
obstacle-challenge/parking_camera_ calibration.json (https://github.com/teddriveomo/wro-2026-future-engineers/blob/main/src/apac-2026/obstacle-challenge/parking_camera_calibration.json) | Raspberry Pi 5 | The team's image-to-floor calibration for the parking modules (1280 × 720 image, 100 × 150 cm rectangle)
tools/lab-calibration.py (https://github.com/teddriveomo/wro-2026-future-engineers/blob/main/src/apac-2026/tools/lab-calibration.py) | Pi or laptop | Interactive Lab colour-threshold picker (trackbars), with the same image preprocessing as main.py ; how it is used at a venue is in vehicle §4 (https://github.com/teddriveomo/wro-2026-future-engineers/blob/main/docs/apac_2026_vehicle.md)
tools/camera-settings.py (https://github.com/teddriveomo/wro-2026-future-engineers/blob/main/src/apac-2026/tools/camera-settings.py) | Pi or laptop | Interactive brightness, contrast and gamma preview

### Serial link

115200 baud. main.py opens /dev/ttyUSB0 on the Pi ( COM3 is its Windows bench setting).

Pi to ESP32: speed,direction,steer and a newline. speed is the 8-bit PWM duty (0 to 255); steer is a correction of -60 to +60 around the servo centre of 85.
ESP32 to Pi: telemetry lines T,seq,ms,heading,left,center,right,validMask,hardStop,appliedSpeed .

### Settings as committed

Setting | Value | File
Drive speed | SPEED = 215 (84 % duty) | main.py
Turning, parking, collision escape | 100 , 70 , 80 | main.py
Leave the parking area at the start | ENABLE_PARKING_EXIT = True | main.py
Park at the end | ENABLE_PARKING_IN = True : after the twelfth corner main.py hands over to a parking module, chosen by PARTIAL_PARKING = True and PARALLEL_PARKING = False as committed (exactly one must be on; software §8) (https://github.com/teddriveomo/wro-2026-future-engineers/blob/main/docs/apac_2026_software.md) | main.py

Setting | Value | File
Run log | ENABLE_RUN_CSV_LOGGING = False ; set to True , every run writes run_logs/round2_run_<date_time>.csv beside main.py , one row per telemetry sample and one per event | main.py
Parking modules | run on their own, e.g. python parallel_parking.py --direction clockwise --last-pillar auto | parallel_parking.p y , partial_parking.py
Parking run log (CSV and video per run) | ENABLE_RUN_LOGGING = False | parallel_parking.p y
Servo centre | SERVO_CENTER = 85 in the Obstacle firmware; 106 in the Open Challenge firmware | firmware
Mux channels | TF-Luna left 0, centre 3, right 2; BNO055 4 | firmware
Front hard stop | disabled since 2026-09-10 ( forwardHardStopIsActive() returns false ); see vehicle §7 (https://github.com/teddriveomo/wro-2026-future-engineers/blob/main/docs/apac_2026_vehicle.md) | firmware

Both parking modules read parking_camera_calibration.json beside them. It depends on how the camera is mounted: the team's file, made on the practice mat with the September camera mount, is committed; python
parallel_parking.py --calibrate makes a new one if the mount changes.

On the Pi, main.py sets GPIO3 high once it has initialised and is waiting for the start signal, and low when it exits.

### Provenance and checksums

The files come from the team's working copy of the code (the coach's repository, commit 63c2b31 , with the team's later changes) as of 23 September 2026. They are stored byte-for-byte (see .gitattributes (https://github.com/teddriveomo/wro-2026-future-engineers/blob/main/src/apac-2026/.gitattributes) ), so these MD5s can be checked on any checkout:

File | MD5
main.py | 77187817b99846d4c7d8766d5e9b8bf7
obstacle-challenge-final-code.ino | a0bf8c1ca5330442bed69d8299892572
lab-calibration.py | aad32eb3ca1954ad38683ee5a004da1a
camera-settings.py | f02e7f9eaae329e8867e965ac4f98511
parallel_parking.py | 9d622df00da023df403fc06669c3c014
partial_parking.py | 34bb36075c2ab680220bd6557056992a
open-challenge.ino | caf69d495f3d0f259a796dfcb81e5b5c
parking_camera_calibration.json | d2ebad50bf7a573496625ee7d20f26da

Not included, because none of them runs on this vehicle: the build without LEDs, the firmware and the Open Challenge variant for a smaller robot, backup copies, component tests, experiments ( main_backgroung_notworking.py ,
corner_slot_filler.py , parking_entry_only.py , parking_exit_only.py , cornering_sequence.py ) and the HSV and RGB
colour tools.

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

## 07 Validation

What the car's own logs show, 15 to 22 September (criteria 3 and 4).

Scope. What the car's own logs record from 15 to 23 September 2026: 260 runs of main.py ( round2_run_*.csv , one row per telemetry sample and one per event, written when ENABLE_RUN_CSV_LOGGING = True ) and 32 attempts of
parallel_parking.py ( parking_run_*.csv , ENABLE_RUN_LOGGING = True ). Every figure here is computed from those files
by run_metrics.py (https://github.com/teddriveomo/wro-2026-future-engineers/blob/main/src/apac-2026/tools/run_metrics.py) . The per-run summary is data/run_summary_2026-09.csv (https://github.com/teddriveomo/wro-2026-future-engineers/blob/main/docs/data/run_summary_2026-09.csv) , the parking attempts are in
data/parking_runs_2026-09-20/ (https://github.com/teddriveomo/wro-2026-future-engineers/blob/main/docs/data/parking_runs_2026-09-20) , and data/example_full_run_20260919_192712.csv (https://github.com/teddriveomo/wro-2026-future-engineers/blob/main/docs/data/example_full_run_20260919_192712.csv) is the fastest full run, whole. The
code was tuned from day to day, so each day's figures belong to that day's settings.

### 1. Full runs from the parking lot

A run counts here when it starts with the parking exit (first state PARKING_EXIT_DIRECTION). It reached the twelfth corner when corner_counter reached 12; the time is counted from the first drive command. Runs the team stopped by hand are included, so the counts are attempts, not a success rate.

Day | Runs | Reached the 12th corner | Time to the 12th corner, s: median (range)
15 Sep | 22 | 1 | 241 (241–241)
16 Sep | 53 | 2 | 225 (201–248)
17 Sep | 15 | 2 | 206 (204–208)
18 Sep | 39 | 9 | 180 (165–190)
19 Sep | 51 | 10 | 167 (154–184)
20 Sep | 7 | 3 | 176 (168–180)

From 15–17 to 18–20 September the time to the twelfth corner fell from 201–248 s to 154–190 s (median 176 s over 22 runs); 14 of those 22 runs reached the twelfth corner inside 180 s, the length of a round.

### 2. Why full runs stopped, 18–20 September

The code prints a reason with every FAULT. Reasons in the full runs of 18–20 September:

Reason | Runs
corner clearance reverse made no reliable progress | 7
parking-exit forward heading alignment timeout | 4
front reached 5 cm before parking alignment | 1
unknown Round 2 state STRAIGHT | 1
parking-exit reverse heading alignment timeout | 1
red approach exceeded 4s without reaching distance trigger | 1

The most frequent, the corner-clearance reverse that made no progress, is the stall of a car pressed against a wall at a corner.

### 3. Parking

U-turn parking-in in main.py , 17 September. 24 test runs of the U-turn routine; 0 reached COMPLETE. The faults were clearance limits during the U-turn (U-turn forward clearance only N cm: 5; U-turn side clearance only N cm: 3; U-turn heading did not complete; progress=N: 1). Earlier that evening, 10 runs of the timed routine (reverse at full left lock, then right) reached COMPLETE in 9; the log cannot show whether the car ended inside the space.

parallel_parking.py , 20 September. 32 attempts from 14:36 to 17:35; 15 reached COMPLETE, in a median of 31 s (20– 88 s). In the last session, from 16:30, 7 of 11. The attempts that did not finish stopped in TRACK_OPENING (5),

ALIGN_VIRTUAL_CUTOUT (5), ENTER_SPACE (3), PARALLEL_ALIGN (2), PASS_LAST_PILLAR (1), FAULT (1).

Three laps, then parallel parking, 20 September. In 3 runs main.py handed over after the twelfth corner (PARKING_PARALLEL_HANDOFF) and parallel_parking.py took over; 2 of them ended parked:

Start | Time to the 12th corner, s | Parking | From the first drive command to the end, s
17:12 | 168 | COMPLETE after 58 s | 226
17:26 | 180 | TRACK_OPENING after 13 s | 193
17:32 | 176 | COMPLETE after 88 s | 264

At those speeds three laps plus parking took longer than a three-minute round.

### 4. After the side rollers came off, 22 September

7 short runs in the evening, each started on a straight (DETECT_DIRECTION) with a 2-corner limit, as the counters show; 5 reached COMPLETE. CORNER_CLEARANCE_RECOVERY ran in 5 of them, and in 5 the car went on to make its turn.

### 5. What the logs do not show

Whether a pillar or a wall was touched: the logs record states, distances and commands, not contacts.
How squarely the car ended in the parking space.

### 6. Performance videos

Challenge | Video | Run
Open Challenge | youtu.be/PbOQJ54wr-0, 33 s | India National Championship, August 2026 (first vehicle)
Obstacle Challenge | youtu.be/dBjqMQ-jRBA, 100 s | India National Championship, August 2026 (first vehicle)

Additional footage: video/apac-2026-obstacle-run.mp4 (https://github.com/teddriveomo/wro-2026-future-engineers/blob/main/video/apac-2026-obstacle-run.mp4) , 3 min 19 s, shows the APAC vehicle on the practice mat, about 20 September: from the parking lot, three laps (12 corners), then a stop after the twelfth corner.

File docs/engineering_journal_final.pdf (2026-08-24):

TEAM TED DRIVE | WRO FUTURE ENGINEERS 2026

WRO FUTURE ENGINEERS 2026

# FINAL ENGINEERING JOURNAL

## TEAM TED DRIVE

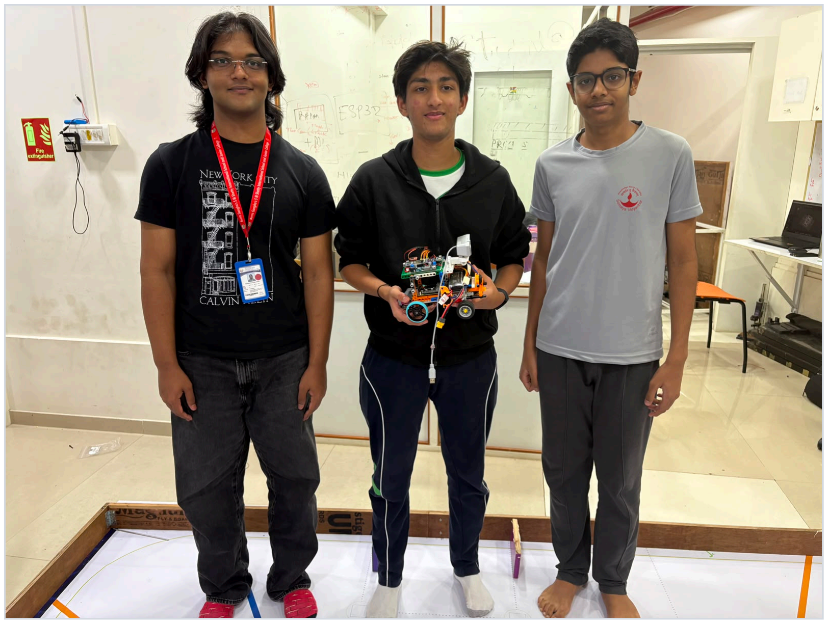
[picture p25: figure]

Formal team photograph with the final competition vehicle

Team members

Ethan Fernandes — Software · Tejas Sirikonda — Mechanical · Diaan — Electronics

Coach | Amey Chavan (OMOTEC)
Competition | WRO Future Engineers 2026 · India Nationals, Hyderabad
Competition dates | 26–28 August 2026
| Repository: github.com/teddriveomo/wro-2026-future-engineers
Prepared 24 August 2026 (rev 3) against WRO 2026 General Rules, Appendix C (Engineering Journal evaluation).

## 01 Project Snapshot

A concise map of the final system, evidence and current validation state

Our vehicle is a fully autonomous four-wheel car built around a rigid LEGO Technic hybrid frame, single-servo Ackermann steering and a rear-drive differential. An ESP32 performs the time-critical sensing and steering loop, while a Raspberry Pi 5 handles pillar perception. The architecture was intentionally split so that a slow or failed vision process cannot stall steering.

Item | Final / current state
Final robot mass | 785 g, including competition electronics and battery
Open Challenge | Implemented and tested; latest reported three-lap result: 24 s
Obstacle Challenge | Competition stack committed at src/Round 2/competition/: ESP32 firmware (test.cpp — PID heading hold, 14-state machine, reverse-arc corners, PAUSE→PASS→SIDE→YAW-BACK pass sequence) + Pi detector (detecttor.py — 2-class green/red ONNX, 5-of-7 vote, 7-column offset LUT). Earlier stacks (3-class detector line, CIELab picker) retained in-repo as evidence. Final timed track test pending.
Parking | Parking-lot start / exit implemented in the competition firmware (boot S-curve: reverse → 45° swing → straight leg → align, heading-verified). End-of-run parallel park-in: shimmy controller written but not yet run (branch feat/round2-park); magenta bay-marker detection exists in the 3-class detector line.
Main power switch | Installed on final vehicle (with separate start button — WRO two-button start sequence)
Steering | MG90 metal-gear servo; Ackermann; 64–136° travel about a 106° centre
Range / heading | 3× TF-Luna through PCA9548A + BNO055 absolute yaw
Compute | ESP32 for motion; Raspberry Pi 5 for vision
Drive | N20 DC motor → TB6612FNG → 20T:28T → LEGO differential

WRO documentation target. Appendix C awards up to 6 points each (scored 0/2/4/6) for Mobility, Power/Sensors, Software/Obstacle Strategy, Systems Thinking, and Reproducibility/GitHub Quality. This journal is organised in exactly those five areas and emphasises decisions, tests, iterations and rebuildability rather than appearance alone.

Section | What the judges can find
1. Mobility & Mechanical Design | Chassis, drivetrain, steering geometry, torque/traction/speed derivation, CAD of printed parts, mechanical iteration, final mass
2. Power & Sensor Architecture | Power tree, sensor selection, placement, I²C architecture, calibration and failure handling
3. Software & Obstacle Strategy | Control-design rationale (P vs PID), Open control flow, firmware logic excerpt, Round 2 state machine, perception pipeline with code, tuning evidence
4. Systems Thinking & Engineering Decisions | Constraints, trade-offs, rejected alternatives, iteration cycles and risk mitigation
5. Reproducibility & GitHub Quality | Repository structure, code/CAD/wiring/video evidence, environment and rebuild workflow
Testing & Final Status | Latest Round 1 result, pending Round 2/parking, pre-competition verification items

## 02 Engineering Process

The journal records how the design changed, not only what the robot looks like now

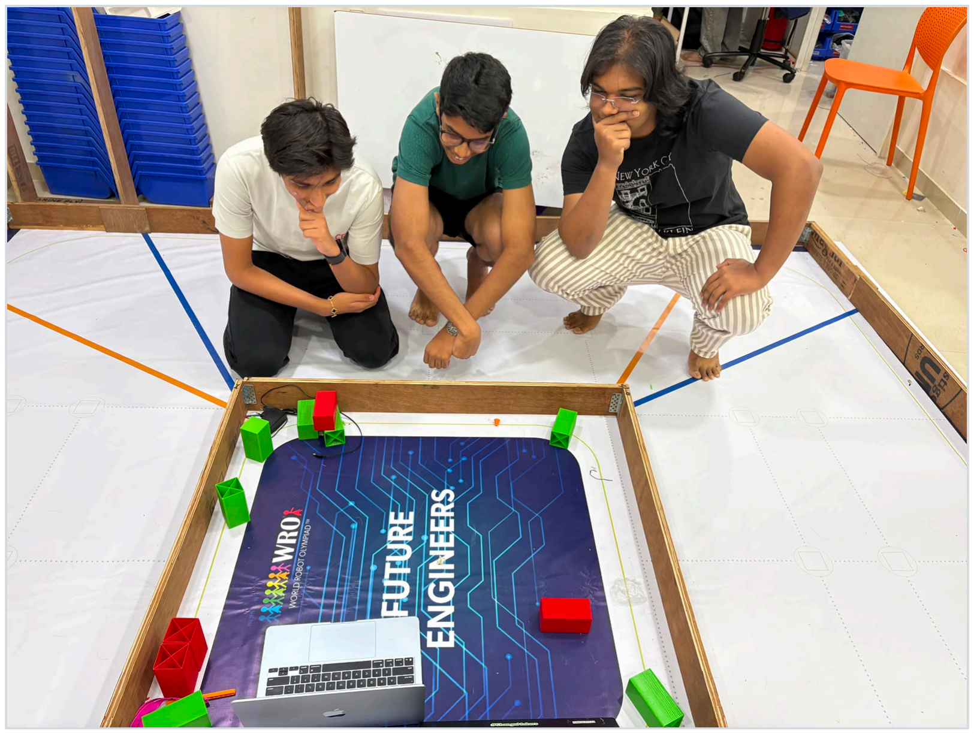
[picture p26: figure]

Informal engineering-session photograph: reviewing the field, pillar placement and robot behaviour during development

The project progressed through repeated plan–build–test–improve cycles. Several ideas that looked correct on paper were changed after measured failures. We deliberately kept those reversals in the repository because they explain why the final system exists in its present form.

### Engineering iteration timeline

Date | Milestone
26 Jun | Initial motion firmware — heading hold + corner detection
19 Jul | HSV pipeline measured; failure modes quantified
26 Jul | Clean dataset split rebuilt after leakage audit; NanoDet line adopted
5 Aug | Field stack reworked; repo restructured to the five-criterion layout
9–10 Aug | Chassis stiffness redesign validated; steering retune + correction-sign fix
11–12 Aug | CAD collected, videos recorded/uploaded, magenta class added, documentation snapshot
19 Aug | 3-class YOLO26n v2 retrained on the leakage-fixed split (Colab, 80 epochs)
21 Aug | Round-1-lineage obstacle firmware + Pi vision sender committed and merged to main
24 Aug | Competition Round-2 stack committed (src/Round 2/competition/); capture tooling merged; final journal rev 3

### The strongest iteration examples

Corner detection changed from a level test to a rising-edge event because a level condition repeatedly stepped the target heading and could make the robot spin.
The first LEGO frame flexed under drivetrain load and shed wheels. Instead of immediately replacing it with a printed chassis, we redesigned the LEGO space-frame to be much stiffer; later sustained runs no longer lost wheels.

The first neural pillar detector performed well on the clean validation split but transferred poorly to real field footage. We fell back to a per-venue calibrated CIELab colour picker, retrained a 3-class YOLO26n on a leakage-fixed split, and finally converged on the 2-class grid/pause-pass competition stack — every stage is kept in the repository as evidence (§08–§09).
The steering correction sign was inverted until the 10 Aug retune — the servo initially fought the heading error instead of nulling it. Caught on the mat, fixed in one commit, and documented rather than hidden (§07). Sensor power routing was reworked so the MG90 servo receives 5 V from the supply rail while the ESP32 provides only the control signal, reducing a previously identified failure path.
A dedicated main power switch has now been installed on the final vehicle, completing the WRO start sequence alongside the separate start button.

## 03 Criterion 1 — Mobility & Mechanical Design

How the chassis, drive and steering were chosen, measured and refined

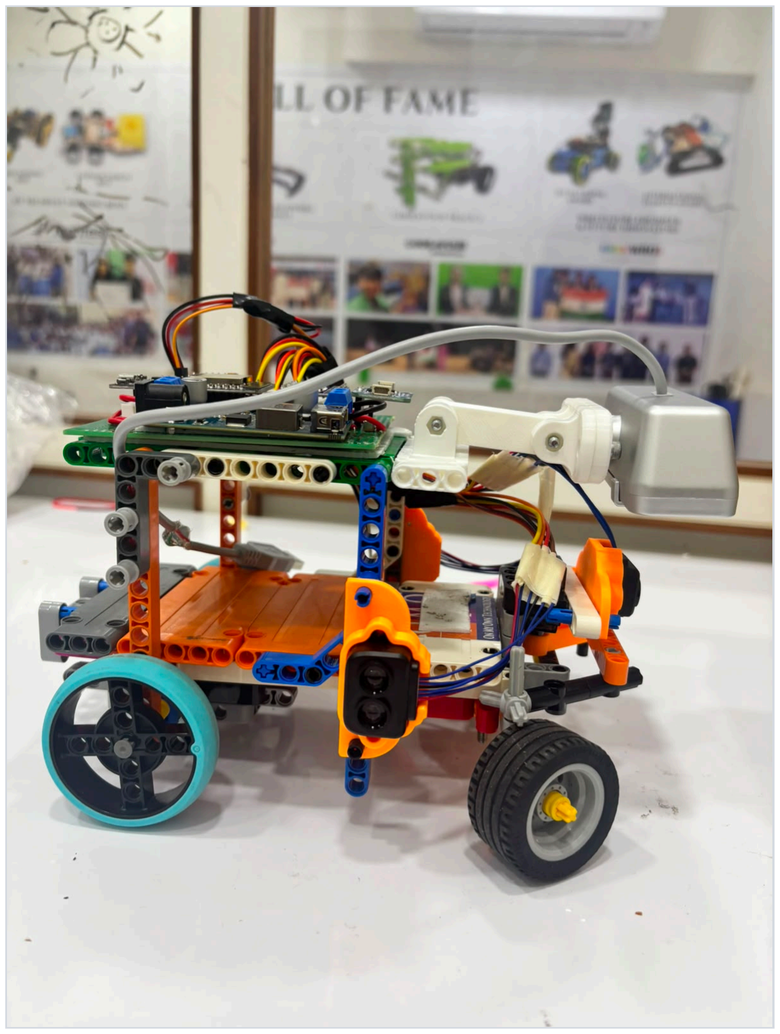
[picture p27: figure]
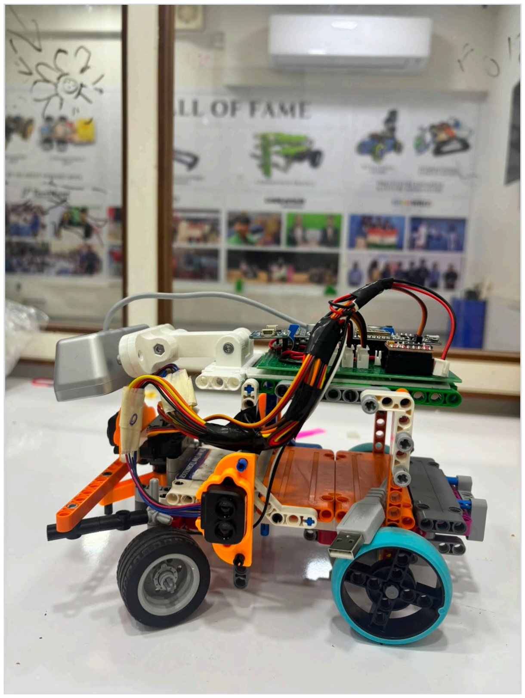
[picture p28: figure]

Side view: electronics stack, rear drive wheel and front steering Opposite side: camera mount, LiDAR and drivetrain packaging

### Final mechanical architecture

Subsystem | Final design | Engineering reason
Chassis | Rigid LEGO Technic hybrid space-frame with printed mounts | Rebuildable, light and sufficiently rigid after the flex-induced wheel-loss failure was diagnosed.
Steering | One front steered axle, single MG90 metal-gear servo, Ackermann linkage | Complies with the non-skid steering requirement and gives a predictable geometric steering response.
Drive | Rear axle driven by one N20 motor through TB6612FNG and LEGO differential | Both driven wheels remain mechanically connected; the differential allows wheel-speed difference during cornering.
External reduction | 20-tooth pinion → 28-tooth crown = 5:7 (1.4:1), counted on the vehicle 11 Aug | Trades some speed for torque/control without needing a drivetrain rebuild.
Wheels | Rear 55.6×14 mm; front 41×21 mm | Larger driven rear wheels improve distance per revolution; smaller front wheels suit the steering geometry.
Mass | 785 g final | Only 52.3% of the 1.5 kg limit, leaving 715 g of margin.

### Printed parts — CAD (designed in Fusion 360, exported STL, in models/)

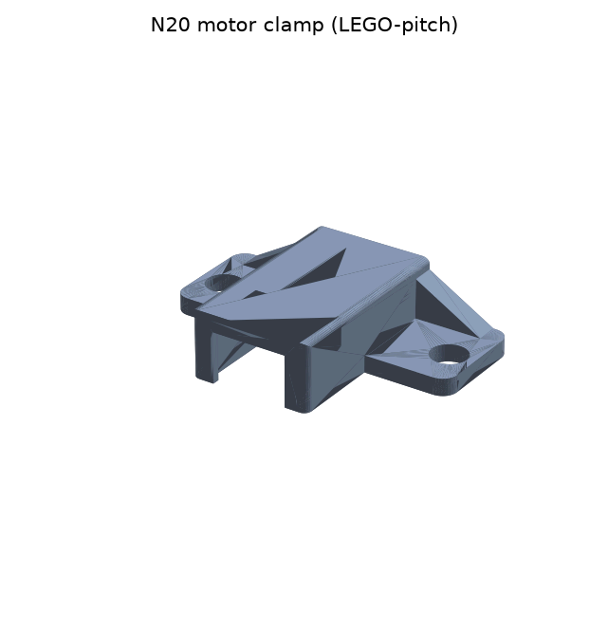
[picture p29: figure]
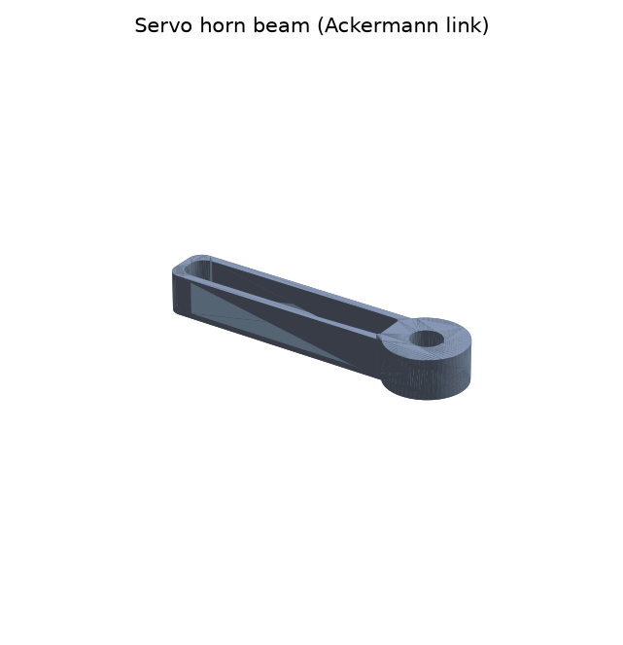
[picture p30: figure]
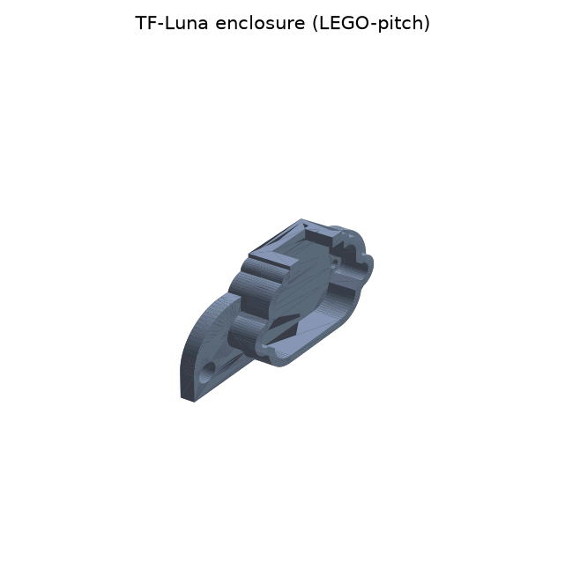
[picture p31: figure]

N20 motor clamp — LEGO-pitch holes | Servo horn beam — Ackermann link | TF-Luna enclosure — LEGO-pitch

Each part solves a LEGO↔commodity-hardware interface: the clamp holds the round N20 body at LEGO pitch, the horn beam converts the servo horn into a Technic-pin link, and the enclosure fixes each TF-Luna's aim height and yaw. The LEGO chassis itself is captured as chassis_lego_current.lxfml plus step-by-step build instructions (PDF) in models/chassis/.

### Torque, traction and acceleration (derived; datasheet-class motor figures, labelled accordingly)

Speed answers "how fast can it go" — this answers "can it get there, and what stops it first." The motor is a GA12-N20-600 class unit: 12 V rated, 600 rpm no-load, 1:50 gearbox, 0.18 kg·cm rated / 0.65 kg·cm stall torque. The external stage multiplies motor torque by Rext = 1.4 (20T→28T, counted on the vehicle):

Motor (datasheet-class) | × 1.4 → wheel | Tractive force at r = 27.8 mm
Rated | 0.18 kg·cm = 0.0177 N·m | 0.0247 N·m | 0.89 N
Stall | 0.65 kg·cm = 0.0637 N·m | 0.0892 N·m | 3.21 N

What stops the vehicle first — and it is genuinely close. The traction limit is μ·Nrear

. At the measured 785 g
with 50–60% of weight on the driven axle and rubber-on-painted-mat μ ≈ 0.5–0.9, the traction ceiling spans roughly 1.9–4.2 N. Against a stall tractive force of 3.21 N the design sits on the boundary: at the slick end the wheels break traction before the motor stalls; at the grippy end the motor stalls first. The distinction is not academic — it decides whether a wall strike stalls the motor (current spike, TB6612 thermal event) or spins the wheels (no spike, but no recovery either). A front/rear axle-load measurement settles the regime and is listed as an open verification (§13).

Acceleration. Motor torque falls roughly linearly from stall toward rated as speed rises; a mid-ramp average of ~2 N on 0.785 kg gives ≈2.5 m/s², so the vehicle reaches its derived 1.15 m/s ceiling in well under a second and under half a corridor width — it is at speed before the first corner, which is why the final run-on behaves as a distance rather than a ramp.

Does the ratio give enough speed? The driving corridor is ~1000 mm inside a 3200 mm mat, so a centre-line lap is roughly 4 × 2.2 m ≈ 8.8 m and three laps ≈ 26 m — about 23 s of pure driving at the 1.15 m/s ceiling before corner slowdowns. The 5:7 stage is therefore not the binding constraint on round time, which is the justification for leaving it rather than re-cutting for speed.

## 04 Steering Control Design & Mechanical Testing

Why the controller is proportional-only, and the test evidence that changed the physical design

### Control design — Round 1: PID evaluated, P-only selected

The steering loop converts wrapped heading error (±180°) into a servo correction. We evaluated the full PID family against the specific structure of this task before choosing the final law:

Term | What it would do here | Decision
P Correction proportional to heading error — restoring | torque toward the target heading. | Kept. Gain = 1.0 servo-degree per degree of error; a 90° corner command drives the servo straight to full lock, so corners need no separate manoeuvre.
I Accumulates error over time to remove steady-state | offset. | Rejected. Our target heading is deliberately stepped by 90° at each corner — a commanded discontinuity. An integrator winds up across the entire transit of every corner and then discharges as overshoot on the next straight. The plant also has no steady-state error source that P + geometry does not already handle.
D | Damps by reacting to error rate. | Rejected. The BNO055 yaw is quantised; differentiating it amplifies quantisation noise into servo chatter, wearing the MG90 and adding jitter on straights.

The final law is P = 1.0 deg/deg with a 2.0° deadband, output clamped to the measured mechanical window 64–136° about the 106° centre (asymmetric −42°/+30°). The deadband suppresses hunting inside the sensor's noise floor; the clamp guarantees no software state can command the linkage past a hard stop. Straight-line gain can then be tuned for stability rather than corner aggressiveness, because corners are executed by the target step saturating the P term — not by a separate turn routine.

Round 2 runs the full PID — and the difference is structural, not taste. The obstacle firmware (src/Round 2/competition/test.cpp) holds heading with Kp = 1.5, Ki = 0.02, Kd = 0.15 on the wrapped ±180° error: P and I are gated by the heading deadband, the integral is hard-clamped at ±50 (anti-windup), and the total correction is clamped to ±20 servo-degrees. Round 2's disturbance profile is different from Round 1's — the pass sequence holds sustained steering offsets and re-join arcs rather than stepping the target, so a derivative term is justified damping the return to the lane, and a small, clamped integral trims residual bias during long offset holds. Both clamps bound each term's failure mode, which is exactly what makes I and D admissible here after being rejected for Round 1. Each round runs the controller its disturbance profile justifies.

Iteration evidence — the sign bug. Until the 10 Aug retune the correction sign was inverted: the servo steered into the error instead of nulling it, and the "centre" and limits were also stale (45–135° about 90° from an earlier linkage). The on-mat symptom — divergence instead of convergence — was traced in one session; the fix (sign flip, centre 106°, limits 64–136°, gain 1.0, deadband 2.0°) is a single documented commit. We kept the wrong version in history because it is the reason the current numbers exist.

### Failure → diagnosis → redesign (chassis)

Stage | Observed evidence | Decision / result
Initial sustained drive | Wheels worked loose from the axles within
seconds.

Treat wheel retention as a frame/stiffness problem, not only a wheel problem.

First proposed fix | A fully 3D-printed chassis was considered to add rigid hubs and retention. | Kept as a fallback, but not committed as the final answer.
Final fix | Ground-up redesign of the LEGO space-frame; tighter packaging and a lower, more rigid load path. | Two later runs of 28 s and 29 s continuous driving recorded no wheel loss; the printed chassis rebuild was cancelled.
Final configuration | Same stiff frame used for all later work; full electronics and camera mounted. | Final competition mass measured at 785 g.

### Latest Open Challenge validation

Test | Result | Interpretation
Three-lap Open Challenge | 24 s total | 8 s per lap average; confirms complete three-lap operation on the latest reported test.
Automatic stop logic | 12 corners observed, then final run-on and braking | Software counts 90° heading steps and stops after the third lap rather than relying on elapsed time alone.
Mass check | 785 g | Large legal margin below the 1.5 kg limit and less load on steering / drivetrain.

Cross-checking the 24 s result against the drivetrain model. 24 s over three laps means the average speed equals the driven lap length ÷ 8 s. On the centre-line estimate (~8.8 m/lap) that would imply ~1.1 m/s — implausibly close to the 1.15 m/s unloaded ceiling — so the result is consistent only with the shorter inner line the controller actually drives after each corner (~6.5–7.5 m/lap), giving a loaded average of 0.8–0.95 m/s ≈ 70–83% of the no-load ceiling. That is aggressive but physically coherent; a tape measurement of the driven line is listed as an outstanding verification (§13), and the loaded straight-line speed itself is re-measured by tape + timer before the rounds. This journal does not carry a straight-line speed number until that measurement exists.

The Open Challenge test is the strongest complete end-to-end validation currently available. The Obstacle Challenge and parallelparking validation are kept separate in later sections because they are not yet complete; this journal does not convert unfinished work into claimed results.

## 05 Criterion 2 — Power & Sensor Architecture

How sensing and power are organised so that the system remains reliable and reproducible

### As-built power architecture

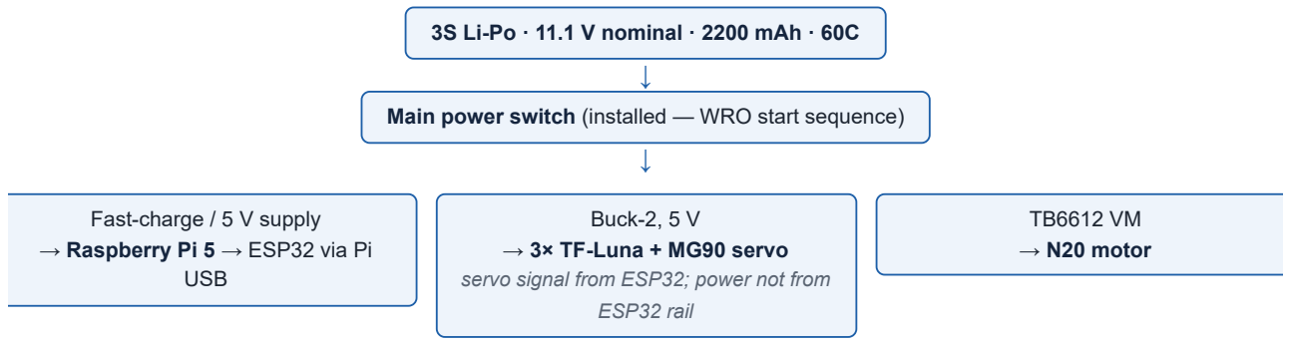
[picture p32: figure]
Fast-charge / 5 V supply → Raspberry Pi 5 → ESP32 via Pi USB; Buck-2, 5 V → 3× TF-Luna + MG90 servo servo signal from ESP32; power not from ESP32 rail; TB6612 VM → N20 motor

3S Li-Po · 11.1 V nominal · 2200 mAh · 60C

Main power switch (installed — WRO start sequence)

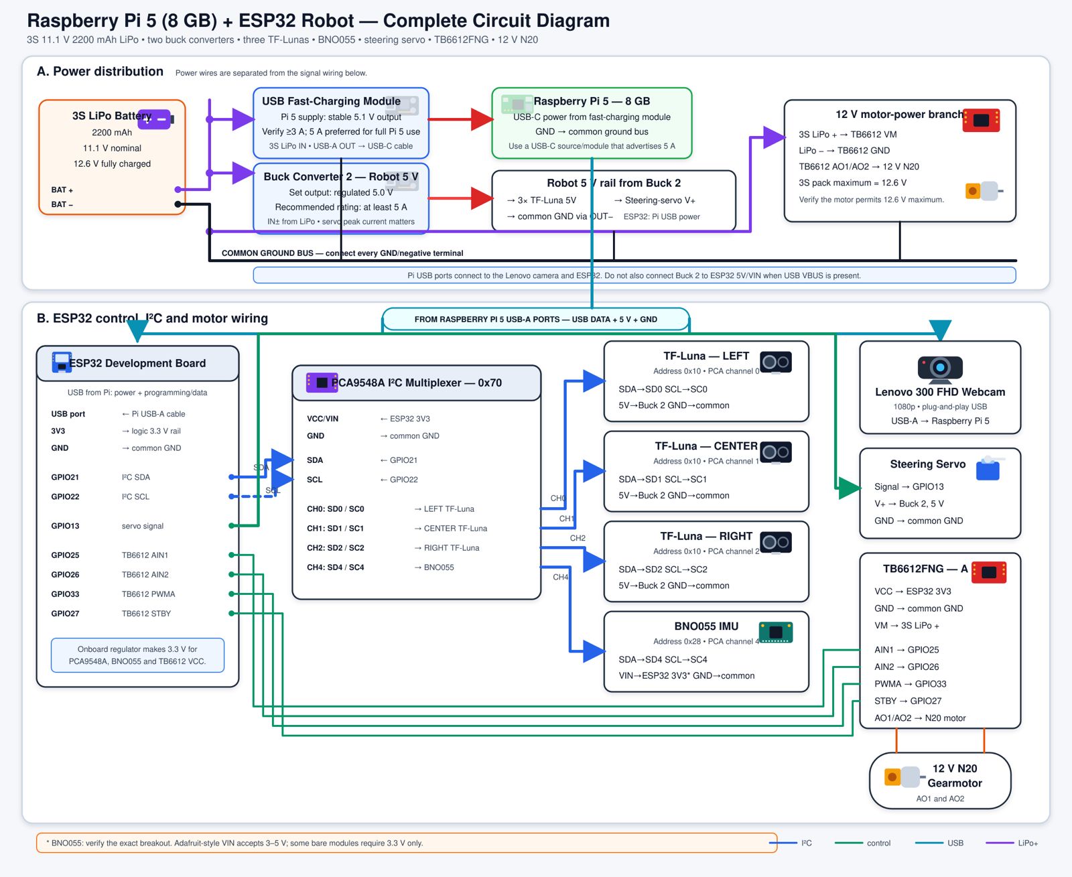
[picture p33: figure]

Complete as-built circuit, photographed 11 Aug; drawn schematics (signal + power, v0.2) are versioned in schemes/

### Power distribution decisions

3S Li-Po pack: 11.1 V nominal, 2200 mAh, 60C.
Main power switch is installed in the final vehicle so the robot can be placed on the field switched OFF, then powered ON before the separate start command.
The Raspberry Pi 5 is powered through the vehicle's regulated 5 V supply; the ESP32 is supplied from the Pi USB path.
A separate 5 V buck rail powers the three TF-Lunas and MG90 servo. The servo control signal comes from the ESP32, but the servo is not powered from the ESP32 rail.
The motor rail feeds TB6612FNG VM and the N20 separately from the 5 V electronics branch, reducing interaction between motor load and sensing/control.
Predicted power budget (derived, versioned in docs/2_power_predicted_budget.md): cruise draw ≈ 0.95–1.5 A at the pack → 23–37 three-minute runs per charge on 1760 mAh usable. Perception (Pi + camera) costs ≈3× propulsion; the binding constraint is Pi 5 thermal throttling (82 °C onset), not pack capacity.

### Sensor map and why each device exists

Device | Qty / bus | Role | Reason for selection
BNO055 IMU | 1 · I²C 0x28 · mux ch4 | Absolute yaw / heading | Avoids three-lap drift associated with integrating gyro rate; heading targets are stepped by exact 90° increments.

TF-Luna LiDAR | 3 · I²C 0x10 · mux ch0/1/2 | Left, centre, right distance | Narrow ~2° beam gives a sharper wall-opening edge than the much wider ultrasonic cone.
PCA9548A | 1 · I²C 0x70 | I²C channel multiplexer | All TF-Lunas share address 0x10, so each must be isolated on its own channel.
USB camera | 1 · Raspberry Pi 5 | Red / green / magenta visual detection | Colour + bearing for obstacles and parking markers.

## 06 Sensor Placement, Calibration & Failure Handling

The sensing layout was designed around field geometry and known failure modes

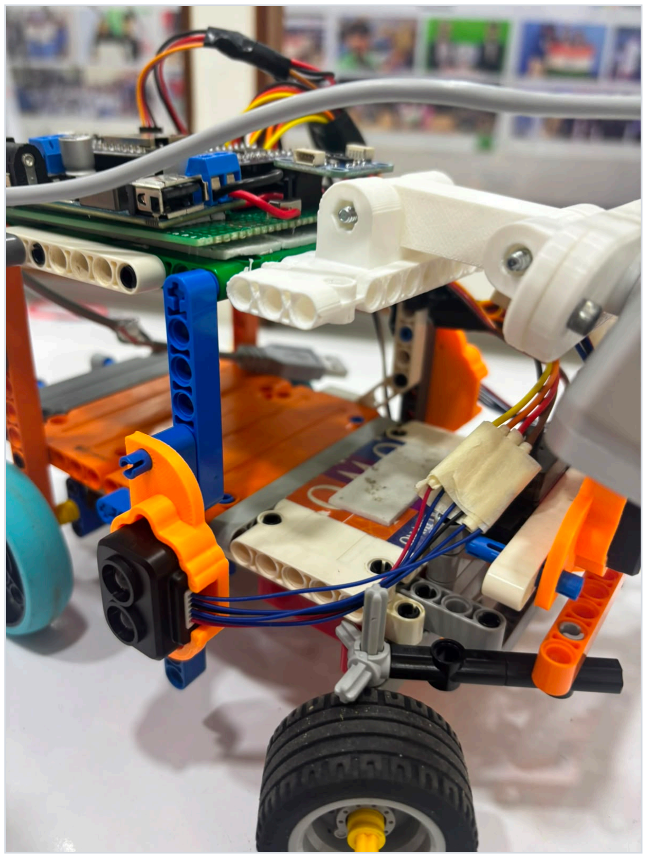
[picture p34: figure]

Front sensor + camera mount as built — TF-Luna aim height and camera pitch fixed by the printed mounts (§03 CAD)

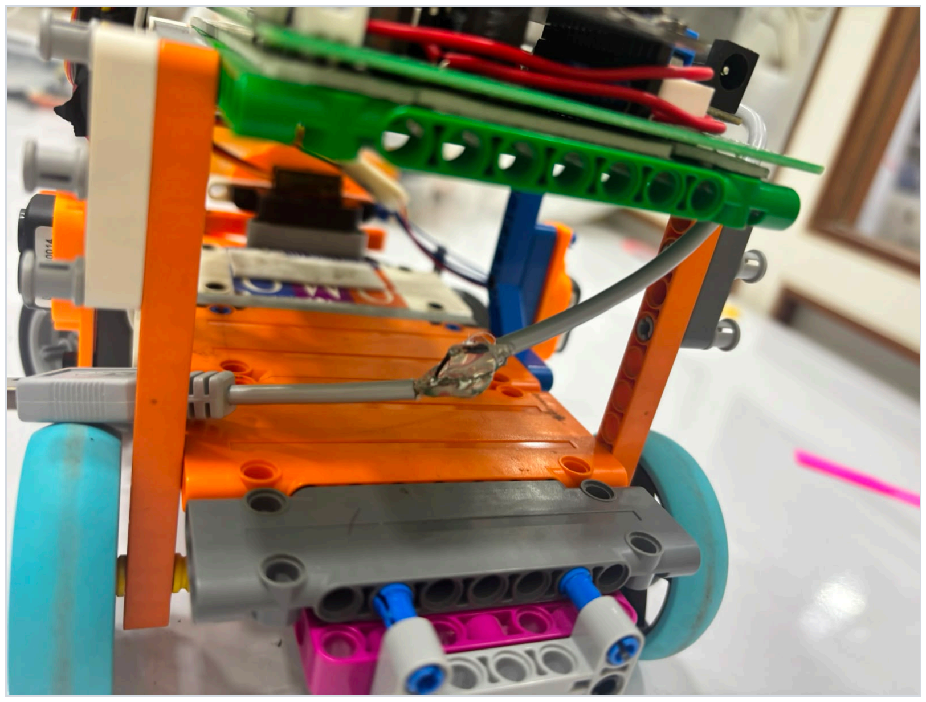
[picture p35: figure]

Chassis midsection: mux, wiring loom and load path


Camera POV — near pillar | Camera POV — mid range | Camera POV — far; sets the minimum detectable box height

### Geometry and bus architecture

The side TF-Lunas watch for the track wall to disappear. A corner is not treated as "distance is large"; it is treated as the transition from wall-present to an opening over 150 cm. That distinction makes sensor placement and beam width more important than absolute range accuracy. The centre TF-Luna provides forward clearance; in Round 2 it is the corner trigger (reverse-arc at 20 cm).

All three TF-Lunas respond at I²C address 0x10, so direct parallel connection would cause an address collision. The PCA9548A solves this by selecting one channel at a time: left on channel 0, centre on 1, right on 2, and the BNO055 on channel 4. The ESP32 I²C bus uses GPIO21 (SDA) and GPIO22 (SCL).

### Calibration and noise controls

BNO055 heading is captured at the start button, after the robot has been positioned on the field, so the reference frame follows the actual starting orientation.
Round 1 accepts a corner only on a rising edge with a 1 s lidar mute; Round 2's corner trigger is the front LiDAR at 20 cm with a 1 s cooldown — in both designs a pillar briefly occluding a side sensor cannot fire a turn.
The competition detector's class map is locked in code ({0: green, 1: red}); the 3-class line's map ({0: green, 1: red, 2: magenta}) is likewise locked, because the exported ONNX carries no name metadata — the constant is always the map in use.
Temporal voting — 5-of-7 agreeing frames with a 70 px spatial lock before a pillar is confirmed, and a 3-frame CLEAR debounce — prevents a single bad frame from commanding or cancelling a pass.
In the 3-class detector line, the magenta parking-marker path includes a dedicated chroma floor and morphological opening to separate marker colour from reflection bleed on the mat.

Failure-aware design. The repository explicitly treats lighting changes, sensor occlusion, I²C address collisions, motor magnetic interference and perception stalls as engineering risks. The two-processor split ensures a perception stall does not block the steering loop.

## 07 Criterion 3 — Software Architecture & Open Challenge

The motion controller is event-driven, heading-based and designed for repeatability

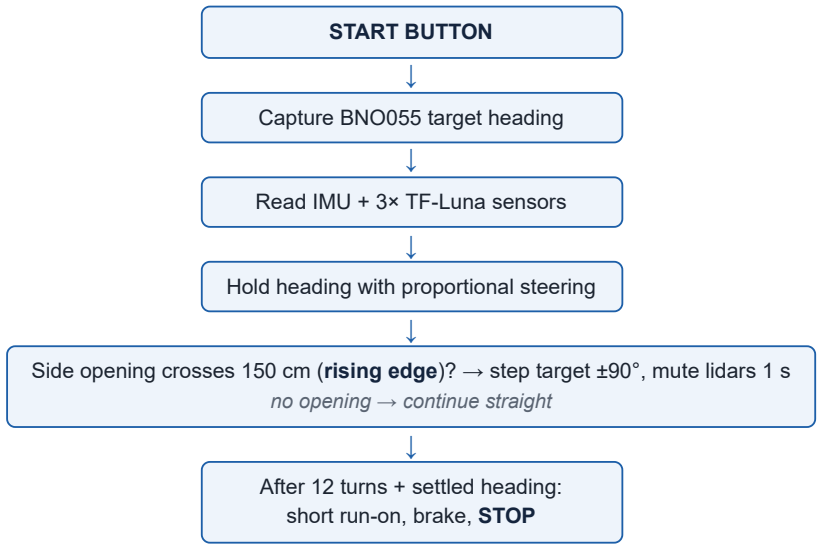
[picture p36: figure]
START BUTTON ↓; Capture BNO055 target heading ↓; Read IMU + 3× TF-Luna sensors ↓; Hold heading with proportional steering ↓; no opening → continue straight ↓; After 12 turns + settled heading: short run-on, brake, STOP

Side opening crosses 150 cm (rising edge)? → step target ±90°, mute lidars 1 s

### Open Challenge algorithm

When the start button is pressed, capture the current BNO055 yaw as the target heading.
Read the IMU and TF-Luna sensors continuously.
Use proportional steering (§04 control design) to reduce wrapped heading error while driving forward. Detect a corner only when a side distance crosses from wall-present to an opening greater than 150 cm.
Step the target heading by +90° or −90° toward the opening; mute the lidars for 1 s so the opening cannot retrigger while it remains visible.
Count the completed 90° target-heading steps. After 12 turns, wait until heading is settled, perform the final short run-on, brake and stop.

Firmware logic — verbatim excerpt from src/Round 1/round 1/round 1.ino (tunables + rising-edge corner detector)

#define SERVO_MAX_ANGLE | 136 | // servo upper limit (deg)

#define SERVO_CENTER | 106 | // wheels-straight angle

#define STEER_GAIN | 1 | // servo deg per deg of heading error

#define OPENING_CM | 150 | // side reading above this = corner/opening

#define TURN_STEP_DEG | 90 | // heading change per detected opening

#define STEER_DEADBAND | 2.0

#define LOOP_DELAY_MS | 20

// ... inside loop(): heading always read, steering always live ... bool lOpen = (l > OPENING_CM);
bool rOpen = (r > OPENING_CM);

bool turned = false;
if (lOpen && !leftWasOpen) { targetHeading -= TURN_STEP_DEG; turned = true; } if (rOpen && !rightWasOpen) { targetHeading += TURN_STEP_DEG; turned = true; }

leftWasOpen = lOpen;
rightWasOpen = rOpen;

if (turned) lidarResumeAt = millis() + 1000; // corner taken -> mute lunas 1 s // during the pause: no reads, no corner detection — but steering stays live int servoAngle = steerToHeading(h, targetHeading);

### Why the rising-edge corner detector matters

A threshold condition such as "if distance >150 cm, turn" remains true for many control cycles while the sensor is looking into the open corner. Without memory of the previous state, the target heading could be stepped repeatedly by 90°, producing a spin. The rising-edge design fires once at the instant the wall disappears (lOpen && !leftWasOpen), then the 1 s lidar mute plus the stored wall state require a genuine new edge before another corner can be detected. Steering remains live throughout the mute — the P-controller saturating against the stepped target is what physically executes the corner.

### Latest measured outcome

The latest team-reported Open Challenge test completed all three laps in 24 seconds (analysed against the drivetrain model in §04). It demonstrates the interaction of chassis rigidity, drivetrain, heading control, corner detection, lap counting and autonomous stop logic rather than testing any one module in isolation.

## 08 Obstacle Challenge Strategy

A staged pass sequence, a PID heading hold and a checksummed serial contract between the two processors

### Perception → decision → actuation pipeline (competition stack, src/Round 2/competition/)

USB camera (Raspberry Pi 5)
↓

2-class ONNX detector — map locked {0: green, 1: red}
↓

5-of-7 temporal vote + spatial lock (70 px) per colour; 3-frame CLEAR debounce
↓

7-column grid LUT on centre-x + closeness bands from box height (22/32/44/58 px) → steer offset + speed per band
↓

Serial contract @115200 with per-line checksums: DRIVE / REVERSE / CLEAR / TRACKING link opens only after ESP_READY → PI_HELLO → ESP_ACK, gated on the pin-32 start button
↓

ESP32 state machine + PID heading hold (§04) → servo + N20

### Implemented state logic (ESP32, 14 states)

State(s) | Purpose | Key behaviour / exit
PARK_WAIT → PARK_REVERSE → PARK_PHASE1 → PARK_STRAIGHT_LEG → PARK_PHASE2 | Start inside the parking lot; S-curve exit at boot | Reverse out of the slot, 45° swing away, forward straight burst, counter-swing to align — heading-verified against the start reference, with an 8 s safety cap
DRIVING_STRAIGHT | PID heading hold and obstacle monitoring | Confirmed pillar → pass sequence; front TF-Luna under 20 cm → corner
PRE_TURN_REVERSE / TURNING | Reverse-arc 90° corner | If a far cube is still in view, IMU reverse on the cardinal first (650 ms, to 28 cm clearance), then the reverse-arc turn; target snapped to the cardinal grid; 1 s cooldown
OBSTACLE_AVOIDING (PAUSE → PASS) | Execute the pass on the commanded side | 400 ms full stop at 45 px box height with pass steer held frozen, then wide pass (full 35° swerve floor) until the cube leaves the camera edge
PI_SIDE → PI_YAW_BACK | Re-join the lane after the cube is off-camera | Drive straight until the matching side LiDAR (red = left, green = right) sees the cube at ≤20 cm — or a 1.6 s cap — then a fixed 28° yaw back toward the lane
PI_REVERSE | Recover when pillar geometry becomes too close | Short 550 ms reverse bursts (max 3), then retry the pass — never latch
ROBOT_STOPPED | End after 12 counted turns (3 laps) | Terminal state

### Obstacle perception and pass-side decision

The Pi runs a 2-class green/red ONNX detector. Each colour keeps a 7-frame history: a pillar is confirmed only on 5-of-7 agreeing frames with a 70 px spatial lock, and a CLEAR must persist 3 frames — a single bad frame can neither command a pass nor cancel one. The nearest confirmed box is placed on a 7-column grid over centre-x with closeness bands from box height; the LUT emits a steering offset (up to the full 35° swerve for both colours — an earlier on-robot LUT that peaked below full lock let the body clip the cube, which is why the floor is now 35°) and a band speed. Red passes right, green passes left. At 45 px box height the sequence inserts a deliberate 400 ms full stop with the pass steer frozen, then commits to the wide pass; after the cube leaves the frame the firmware goes straight until the matching side LiDAR confirms the cube alongside, then yaws back a fixed 28°. A segment allows at most 2 passes before the next corner.

Pi-side detection & pass-side decision — verbatim excerpts from src/Round 2/competition/detecttor.py

ONNX_MODEL_PATH = "best_ncnn.onnx"
CLASS_NAMES = {0: "green", 1: "red"}
VOTE_HISTORY = 7
MIN_VOTES = 5
CLEAR_HISTORY = 3
LOCK_MATCH_PX = 70
SWERVE_HEIGHT_PX = 45 | # start the pass only when the cube is this tall
ALIGN_PAUSE_S = 0.40 | # stop 400 ms at 45px, then swerve
GREEN_MIN_OFFSET = 35 | # green pass-left needs full DIFF or the body clips
RED_MIN_OFFSET = 35 | # red pass-right, same full swerve
# ... main loop: confirmed 5-of-7 per colour, nearest actionable box wins ...

cmd = (
f"DRIVE,{primary_color},{cmd_info['speed']},{cmd_info['offset']}," f"{cmd_info['phase']},{active_box['height']}"
)
if cmd != last_sent or due:
serial_write(cmd)
elif decision == "CLEAR" and clear_counter >= CLEAR_HISTORY:
serial_write("CLEAR")

Model file: the weights sit next to the script under the name in ONNX_MODEL_PATH; the 3-class v2 weights versioned in ../detector/models/ decode green/red at the same indices (0/1) if substituted — the extra magenta class is simply ignored by this map. Lineage: the 3-class detector line (with its leak-fixed per-class metrics, §09) and the venue-calibrated CIELab picker are retained in-repo as the measured evolution behind this stack.

Current validation status. The competition stack is committed and the components are individually exercised, but the final timed Round 2 track test has not yet been completed. This journal describes the implemented architecture and its component-level evidence without inventing a final race result.

## 09 Vision Iteration & Data-Driven Decisions

The final perception method was chosen after multiple approaches were measured and rejected


Live detection on the Raspberry Pi 5 — dual-pillar frame with class + confidence overlay (bench setup in docs/img/)

### Detector evolution

Iteration | Evidence | Engineering response
HSV / connected components | Very fast (~0.43 ms/frame), but failed with both missed pillars and false positives. | Could not be rescued by a downstream verifier because missed proposals never reach the verifier.
tiny_pillar (111K params) | Lower wrong-side rate, but 9.7% no-call and lower overall decision performance. | Rejected in favour of stronger decision coverage.
nanodet_lite (1.17M params) | Clean-split macro F1 0.898 and pass-side accuracy 0.941; beat tiny model on six of seven metrics. | Selected as the neural winner on validation data.
Field transfer check | Neural winner failed to transfer reliably to real field footage; repository had already documented the one-session-data limitation. | Per-venue calibrated CIELab picker adopted as the interim competition stack; failed neural path preserved as evidence.
Magenta extension | Close-range reflection bleed joined marker colour into a large blob. | Dedicated magenta class, stronger chroma floor and morphological OPEN; parking-marker telemetry added.
3-class YOLO26n-320 v2 | Retrained 19 Aug on the leakage-fixed, group-wise split, 80 epochs: mAP50-95 green 0.859 / red 0.792 / magenta 0.820. | Adopted for the 3-class detector line; weights (.onnx + .pt) and harness versioned in-repo.
Grid / pause-pass competition stack | 2-class green/red ONNX with 5-of-7 vote + spatial lock; 7-column offset LUT with closeness bands; staged PAUSE→PASS→SIDE→YAW-BACK pass paired with the PID firmware. An earlier on-robot LUT peaked below full steering lock and let the body clip cubes — the offset floor is now the full 35°. | Committed as the flashed Nationals configuration (src/Round 2/competition/, §08); earlier stacks retained as evidence.

### Validation integrity: the split was rebuilt after leakage was found

When validation numbers looked better than real behaviour, the team audited the dataset and found 25 duplicate image stems across the split boundary and 27 of 29 validation time buckets overlapping training. Instead of adjusting the results, all previous numbers were withdrawn. A script then rebuilt a group-wise 473/124 split by capture bucket, and the models were retrained and re-measured. This was one of the most important systemsthinking decisions because it changed which evidence could be trusted — and it is why the v2 per-class numbers above are reported against the fixed split only.

### Why venue calibration was adopted (and kept for the fallback)

Measured colour centres shifted substantially between capture sessions: the repository reports a 24.0-unit movement in the fitted red Lab chroma centre between two sessions, larger than the normal tolerance budget. Condition-matched calibration therefore became a procedure: calibrate in the actual venue light during check time, save the calibration and reuse it headlessly for the run. This converts lighting from an uncontrolled assumption into a managed setup step — and the same discipline applies to the competition detector: verify it on the actual field in venue light before trusting bench numbers.

## 10 Criterion 4 — Systems Thinking & Engineering Decisions

The robot was treated as one interacting system under constraints, not as separate parts

### Primary constraints

Constraint | Design response
300 × 200 × 300 mm envelope | Compact stacked electronics and narrow chassis; camera and sensor mounts integrated into the frame.
≤ 1.5 kg total mass | Final vehicle is 785 g, leaving 715 g margin for compliance and limiting drivetrain/steering load.
Ackermann / non-skid steering | One steered front axle with MG90 linkage; one mechanically connected rear drive axle through a differential (a differential gear on the driven axle is rule-legal; differential-drive steering is not used).
Full autonomy | Two-button procedure: main power switch followed by the dedicated start button; no manual control during a run.
No wireless during rounds (rule 11.10) | Pi radios disabled for every round; the competition stack opens no network paths — preview is a local window only and headless by default.
Vision compute budget | Raspberry Pi 5 CPU-only; motion remains on ESP32 so perception load cannot block control.
Asymmetric scoring risk | The pass-side system is tuned to avoid wrong-side decisions; an uncertain/no-call is treated differently from a confidently wrong call.
Time before competition | Engineering evidence was versioned continuously in GitHub so design changes and failures were not lost.
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

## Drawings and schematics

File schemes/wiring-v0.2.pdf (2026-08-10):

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

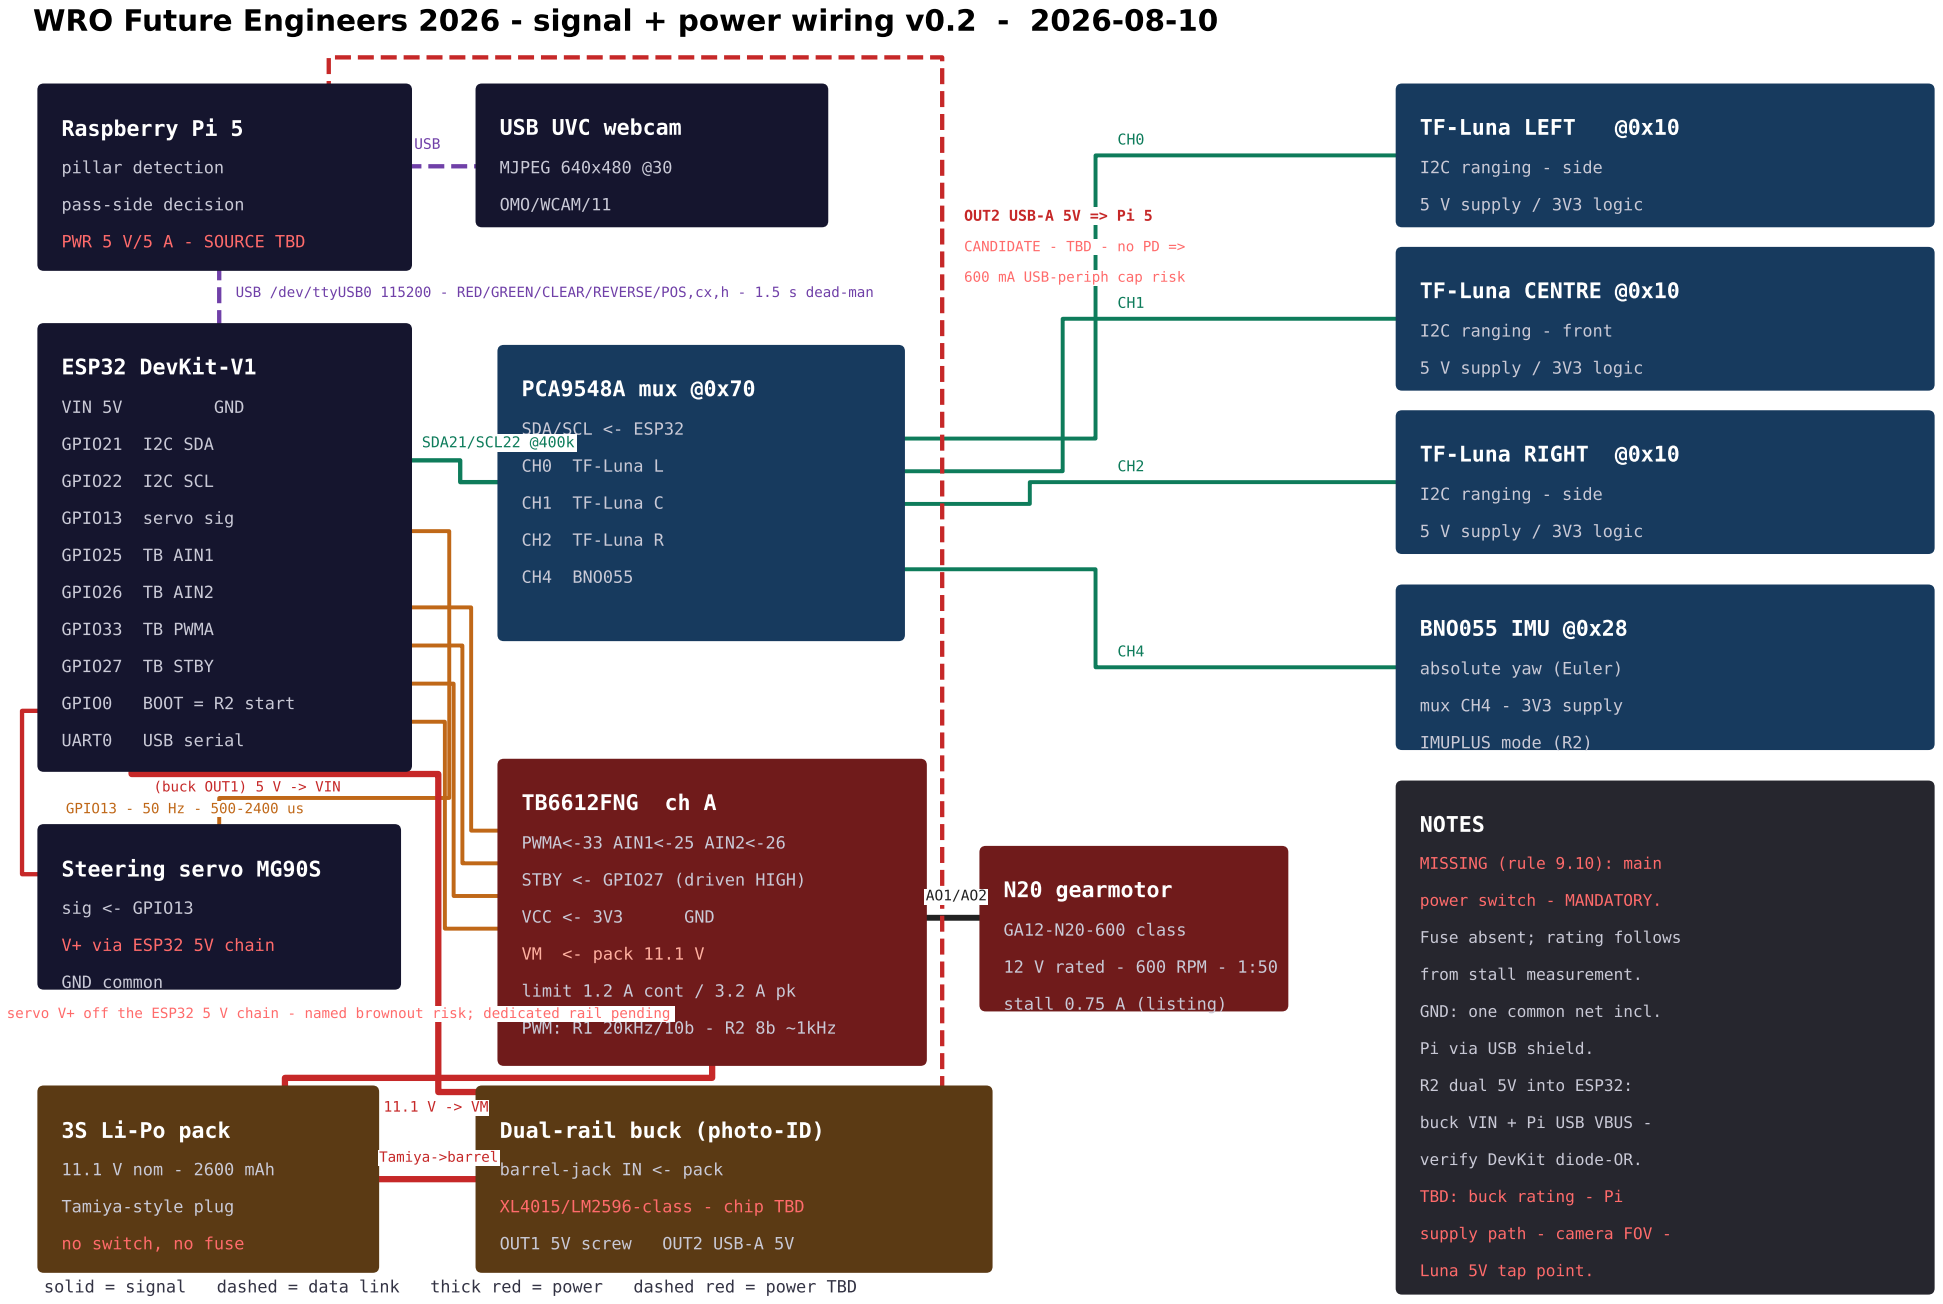
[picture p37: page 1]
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

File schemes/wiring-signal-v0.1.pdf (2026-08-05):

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

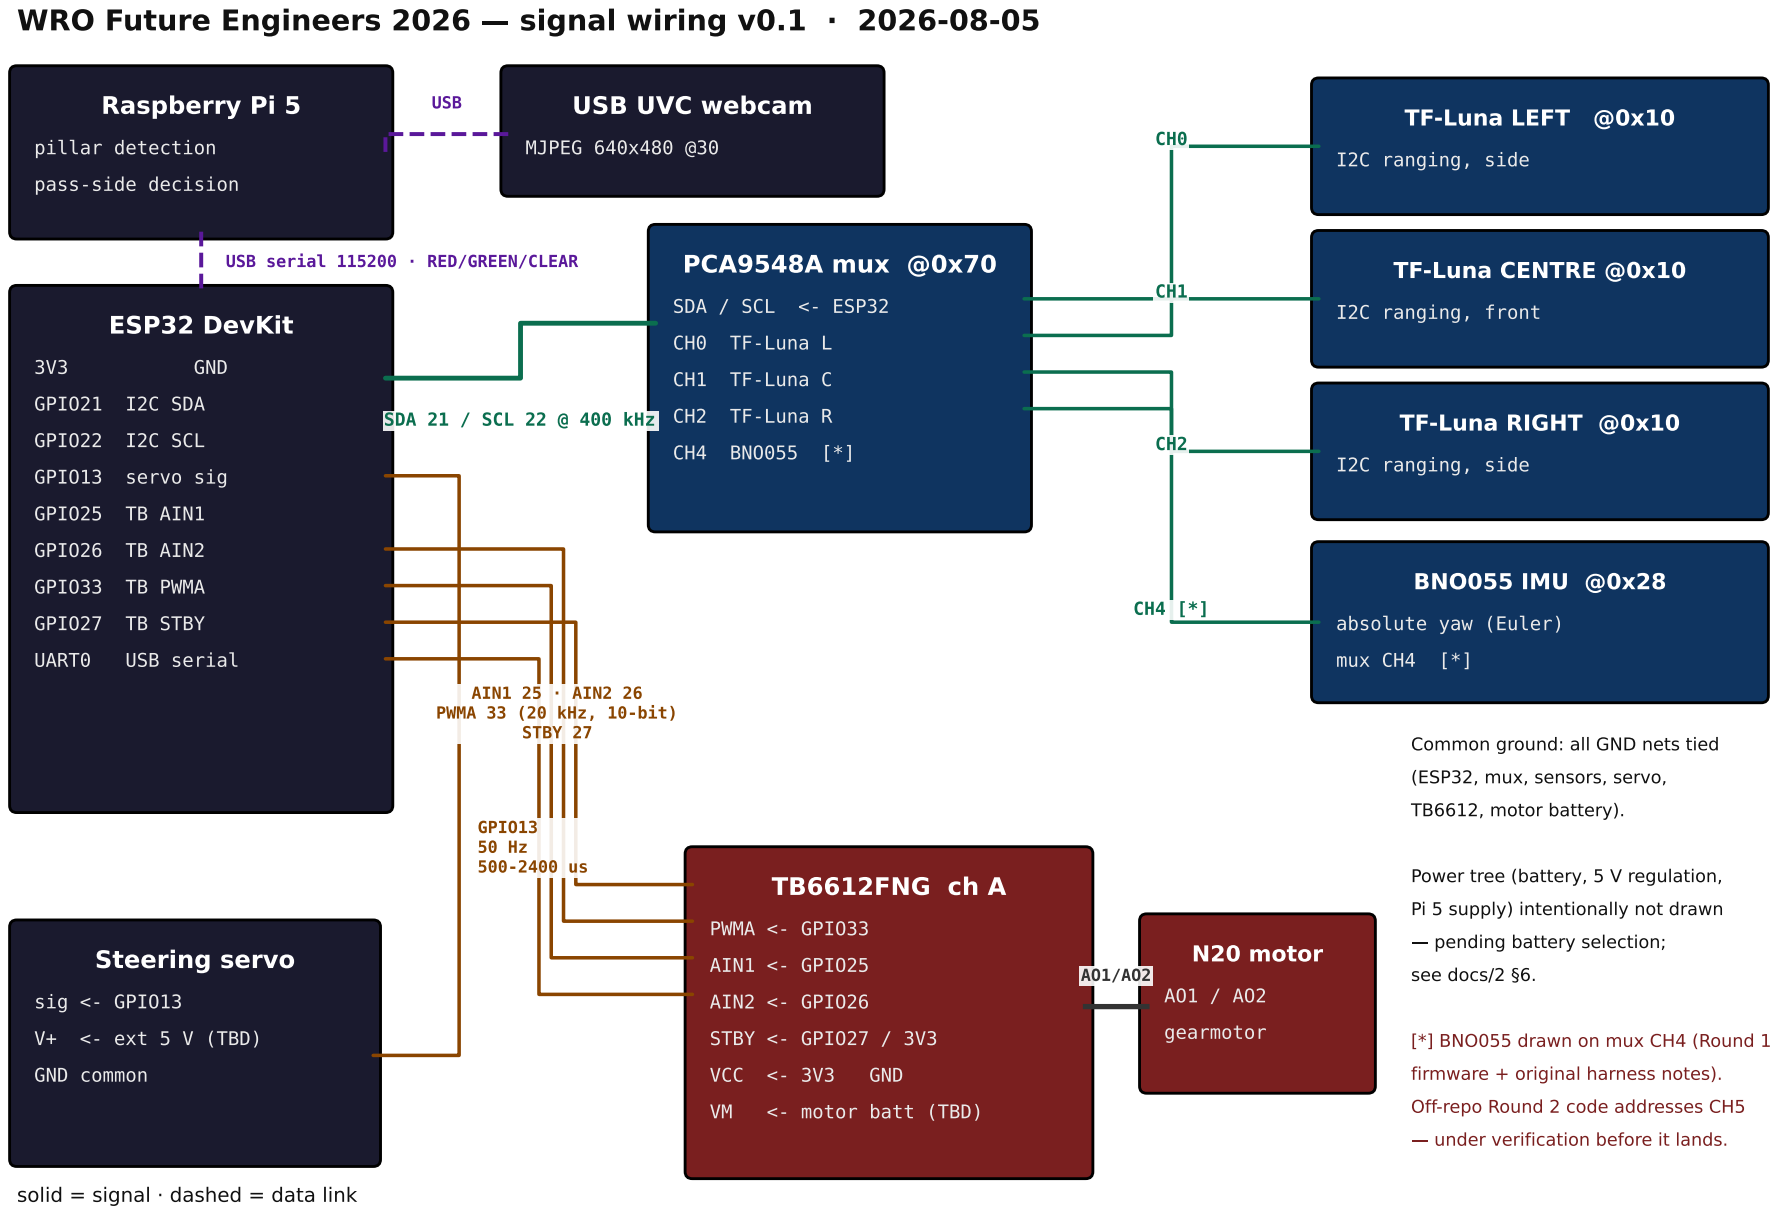
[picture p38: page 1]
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

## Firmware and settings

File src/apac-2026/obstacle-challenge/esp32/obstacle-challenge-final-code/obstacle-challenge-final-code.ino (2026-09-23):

#include <Wire.h>
#include <Adafruit_Sensor.h>
#include <Adafruit_BNO055.h>
#include <Adafruit_NeoPixel.h>
#include <utility/imumaths.h>
#include <math.h>
#include <errno.h>
#include <limits.h>


// =====================================================
// Current hardware pins
// =====================================================
#define LED_PIN 4
#define LED_COUNT 6

Adafruit_NeoPixel strip(LED_COUNT, LED_PIN, NEO_GRB + NEO_KHZ800);

#define I2C_SDA 21
#define I2C_SCL 22

#define SERVO_PIN 13

#define MOTOR_IN1 25
#define MOTOR_IN2 26
#define MOTOR_PWM 33

#define START_BUTTON 32

// =====================================================
// I2C addresses and PCA9548A channels
// =====================================================

#define PCA9548A_ADDRESS 0x70
#define TFLUNA_ADDRESS   0x10
#define BNO055_ADDRESS   0x28

#define MUX_CH_LEFT    0
#define MUX_CH_CENTER  3
#define MUX_CH_RIGHT   2
#define MUX_CH_BNO     4

// =====================================================
// Servo configuration
// =====================================================

const int SERVO_CENTER = 85;
const int SERVO_MIN_PULSE_US = 500;
const int SERVO_MAX_PULSE_US = 2400;
const int SERVO_FRAME_MS = 20;
const int SERVO_MIN_CORRECTION = -60;
const int SERVO_MAX_CORRECTION = 60;

portMUX_TYPE servoMux = portMUX_INITIALIZER_UNLOCKED;
volatile uint16_t requestedServoPulseUs = 1500;
volatile int requestedServoCorrection = 0;

// =====================================================
// Sensors and serial protocol
// =====================================================

Adafruit_BNO055 bno(55, BNO055_ADDRESS, &Wire);

const int INVALID_DISTANCE = -1;
const int INVALID_HEADING = 1000;

const unsigned long DISTANCE_FRESH_MS = 250;
const unsigned long HEADING_FRESH_MS = 250;

const uint8_t VALID_LEFT_MASK = 0x01;
const uint8_t VALID_CENTER_MASK = 0x02;
const uint8_t VALID_RIGHT_MASK = 0x04;
const uint8_t VALID_HEADING_MASK = 0x08;

int distanceLeft = INVALID_DISTANCE;
int distanceCenter = INVALID_DISTANCE;
int distanceRight = INVALID_DISTANCE;

uint8_t leftReadFailures = 0;
uint8_t centerReadFailures = 0;
uint8_t rightReadFailures = 0;

unsigned long leftLastValidMillis = 0;
unsigned long centerLastValidMillis = 0;
unsigned long rightLastValidMillis = 0;

bool leftHasValidReading = false;
bool centerHasValidReading = false;
bool rightHasValidReading = false;

int heading = 0;
uint8_t headingReadFailures = 0;
unsigned long headingLastValidMillis = 0;
bool headingHasValidReading = false;

String commandInput = "";

const unsigned long COMMAND_TIMEOUT_MS = 500;
const int HARD_STOP_ENTER_CM = 18;
const int HARD_STOP_RELEASE_CM = 24;
const unsigned long PARKING_OVERRIDE_TIMEOUT_MS = 10000;
const unsigned int MOTOR_DIRECTION_DEADTIME_US = 2000;

unsigned long lastCommandMillis = 0;
bool commandReceived = false;

bool collisionHardStopLatched = false;
bool reverseReleaseObserved = false;
bool parkingDistanceOverride = false;
unsigned long parkingOverrideLastCommandMillis = 0;

int appliedSpeed = 0;
int appliedDirection = 0;
bool motorBrakeEngaged = false;
int lastNonzeroDirection = 0;
bool hasDriven = false;

uint32_t telemetrySequence = 0;

// =====================================================
// Servo pulse generation on Core 0
// =====================================================

uint16_t angleToPulse(int angle)
{
  angle = constrain(angle, 0, 180);

  return (uint16_t)map(
    angle,
    0,
    180,
    SERVO_MIN_PULSE_US,
    SERVO_MAX_PULSE_US
  );
}

void steer(int correction)
{
  correction = constrain(
    correction,
    SERVO_MIN_CORRECTION,
    SERVO_MAX_CORRECTION
  );

  int angle = SERVO_CENTER + correction;
  angle = constrain(angle, 0, 180);

  uint16_t pulse = angleToPulse(angle);

  portENTER_CRITICAL(&servoMux);
  requestedServoCorrection = correction;
  requestedServoPulseUs = pulse;
  portEXIT_CRITICAL(&servoMux);
}

void servoPulseTask(void *parameter)
{
  TickType_t lastWakeTime = xTaskGetTickCount();
  const TickType_t framePeriod = pdMS_TO_TICKS(SERVO_FRAME_MS);

  while (true)
  {
    uint16_t pulseWidth;

    portENTER_CRITICAL(&servoMux);
    pulseWidth = requestedServoPulseUs;
    portEXIT_CRITICAL(&servoMux);

    digitalWrite(SERVO_PIN, HIGH);
    delayMicroseconds(pulseWidth);
    digitalWrite(SERVO_PIN, LOW);

    vTaskDelayUntil(&lastWakeTime, framePeriod);
  }
}

// =====================================================
// PCA9548A and TF-Luna functions
// =====================================================

bool selectMuxChannel(uint8_t channel)
{
  if (channel > 7)
  {
    return false;
  }

  Wire.beginTransmission(PCA9548A_ADDRESS);
  Wire.write(1 << channel);

  return Wire.endTransmission() == 0;
}

int readTFLuna(uint8_t channel)
{
  if (!selectMuxChannel(channel))
  {
    return INVALID_DISTANCE;
  }

  delayMicroseconds(500);

  Wire.beginTransmission(TFLUNA_ADDRESS);
  Wire.write(0x00);

  if (Wire.endTransmission(false) != 0)
  {
    return INVALID_DISTANCE;
  }

  uint8_t received = Wire.requestFrom(
    (uint8_t)TFLUNA_ADDRESS,
    (uint8_t)9
  );

  if (received < 2)
  {
    while (Wire.available())
    {
      Wire.read();
    }

    return INVALID_DISTANCE;
  }

  uint8_t lowByte = Wire.read();
  uint8_t highByte = Wire.read();

  while (Wire.available())
  {
    Wire.read();
  }

  int distance = ((int)highByte << 8) | lowByte;

  if (distance > 0 && distance <= 500)
  {
    return distance;
  }

  return INVALID_DISTANCE;
}

void updateDistance(
  uint8_t channel,
  int &distanceValue,
  uint8_t &failureCount,
  unsigned long &lastValidMillis,
  bool &hasValidReading
)
{
  int reading = readTFLuna(channel);

  if (reading == INVALID_DISTANCE)
  {
    reading = readTFLuna(channel);
  }

  if (reading != INVALID_DISTANCE)
  {
    distanceValue = reading;
    failureCount = 0;
    lastValidMillis = millis();
    hasValidReading = true;
    return;
  }

  if (failureCount < 255)
  {
    failureCount++;
  }
}

void updateTFLunas()
{
  updateDistance(
    MUX_CH_LEFT,
    distanceLeft,
    leftReadFailures,
    leftLastValidMillis,
    leftHasValidReading
  );

  updateDistance(
    MUX_CH_CENTER,
    distanceCenter,
    centerReadFailures,
    centerLastValidMillis,
    centerHasValidReading
  );

  updateDistance(
    MUX_CH_RIGHT,
    distanceRight,
    rightReadFailures,
    rightLastValidMillis,
    rightHasValidReading
  );
}

bool readingIsFresh(
  bool hasValidReading,
  unsigned long lastValidMillis,
  unsigned long freshnessLimit,
  unsigned long now
)
{
  return hasValidReading &&
         (unsigned long)(now - lastValidMillis) <= freshnessLimit;
}

bool leftIsFresh(unsigned long now)
{
  return readingIsFresh(
    leftHasValidReading,
    leftLastValidMillis,
    DISTANCE_FRESH_MS,
    now
  );
}

bool centerIsFresh(unsigned long now)
{
  return readingIsFresh(
    centerHasValidReading,
    centerLastValidMillis,
    DISTANCE_FRESH_MS,
    now
  );
}

bool rightIsFresh(unsigned long now)
{
  return readingIsFresh(
    rightHasValidReading,
    rightLastValidMillis,
    DISTANCE_FRESH_MS,
    now
  );
}

// =====================================================
// BNO055
// =====================================================

void updateBNO()
{
  if (!selectMuxChannel(MUX_CH_BNO))
  {
    if (headingReadFailures < 255)
    {
      headingReadFailures++;
    }

    return;
  }

  delayMicroseconds(500);

  sensors_event_t orientationData;

  if (!bno.getEvent(
    &orientationData,
    Adafruit_BNO055::VECTOR_EULER
  ))
  {
    if (headingReadFailures < 255)
    {
      headingReadFailures++;
    }

    return;
  }

  float rawHeading = orientationData.orientation.x;

  if (isnan(rawHeading) || isinf(rawHeading))
  {
    if (headingReadFailures < 255)
    {
      headingReadFailures++;
    }

    return;
  }

  heading = (int)rawHeading;

  if (heading > 180)
  {
    heading -= 360;
  }

  if (heading < -180)
  {
    heading += 360;
  }

  headingReadFailures = 0;
  headingLastValidMillis = millis();
  headingHasValidReading = true;
}

bool headingIsFresh(unsigned long now)
{
  return readingIsFresh(
    headingHasValidReading,
    headingLastValidMillis,
    HEADING_FRESH_MS,
    now
  );
}

// =====================================================
// Motor control
// =====================================================

void activeBrakeMotor()
{
  if (motorBrakeEngaged && appliedSpeed == 0)
  {
    return;
  }

  // L293D active brake: both bridge inputs equal while ENA is HIGH.
  analogWrite(MOTOR_PWM, 0);
  digitalWrite(MOTOR_IN1, LOW);
  digitalWrite(MOTOR_IN2, LOW);
  delayMicroseconds(100);
  analogWrite(MOTOR_PWM, 255);

  appliedSpeed = 0;
  motorBrakeEngaged = true;
}

void driveMotor(int speedValue, int direction)
{
  speedValue = constrain(speedValue, 0, 255);

  if (speedValue == 0)
  {
    activeBrakeMotor();
    return;
  }

  bool directionChanged =
    hasDriven && lastNonzeroDirection != direction;

  if (motorBrakeEngaged || directionChanged)
  {
    // Disable the bridge before changing either direction input.
    analogWrite(MOTOR_PWM, 0);
    digitalWrite(MOTOR_IN1, LOW);
    digitalWrite(MOTOR_IN2, LOW);

    if (directionChanged)
    {
      delayMicroseconds(MOTOR_DIRECTION_DEADTIME_US);
    }
    else
    {
      delayMicroseconds(100);
    }
  }

  if (direction == 0)
  {
    digitalWrite(MOTOR_IN1, HIGH);
    digitalWrite(MOTOR_IN2, LOW);
  }
  else
  {
    digitalWrite(MOTOR_IN1, LOW);
    digitalWrite(MOTOR_IN2, HIGH);
  }

  analogWrite(MOTOR_PWM, speedValue);

  appliedSpeed = speedValue;
  appliedDirection = direction;
  motorBrakeEngaged = false;
  lastNonzeroDirection = direction;
  hasDriven = true;
}

void stopMotor()
{
  activeBrakeMotor();
}

void updateHardStopLatch(unsigned long now)
{
  bool centerFresh = centerIsFresh(now);

  if (
    centerFresh &&
    distanceCenter <= HARD_STOP_ENTER_CM &&
    !collisionHardStopLatched
  )
  {
    collisionHardStopLatched = true;
    reverseReleaseObserved = false;
  }

  if (
    collisionHardStopLatched &&
    reverseReleaseObserved &&
    centerFresh &&
    distanceCenter >= HARD_STOP_RELEASE_CM
  )
  {
    collisionHardStopLatched = false;
    reverseReleaseObserved = false;
  }
}

bool forwardHardStopIsActive(unsigned long now)
{
  // Disabled: stopping the drive motor here ends a competition run.
  // Distance telemetry remains available to Python for navigation decisions.
  return false;
}

void enforceSafetyInterlocks(unsigned long now)
{
  if (
    parkingDistanceOverride &&
    (unsigned long)(now - parkingOverrideLastCommandMillis) >
      PARKING_OVERRIDE_TIMEOUT_MS
  )
  {
    parkingDistanceOverride = false;
  }

  updateHardStopLatch(now);

  if (appliedSpeed > 0)
  {
    bool staleHeading = !headingIsFresh(now);
    bool unsafeForward =
      appliedDirection == 0 && forwardHardStopIsActive(now);

    if (staleHeading || unsafeForward)
    {
      stopMotor();
    }
  }

  if (
    commandReceived &&
    (unsigned long)(now - lastCommandMillis) > COMMAND_TIMEOUT_MS
  )
  {
    stopMotor();
    steer(0);
    commandReceived = false;
  }
}

// =====================================================
// Raspberry Pi handshake
// =====================================================

void waitForOK()
{
  String handshakeInput = "";
  unsigned long lastOkMessage = 0;

  while (true)
  {
    if (millis() - lastOkMessage >= 500)
    {
      Serial.println("OK");
      lastOkMessage = millis();
    }

    while (Serial.available())
    {
      char c = Serial.read();

      if (c == '\n')
      {
        handshakeInput.trim();

        if (handshakeInput.equalsIgnoreCase("OK"))
        {
          return;
        }

        handshakeInput = "";
      }
      else if (c != '\r')
      {
        handshakeInput += c;
      }
    }

    delay(1);
  }
}

// =====================================================
// Raspberry Pi telemetry and commands
// =====================================================

void sendSensorData()
{
  unsigned long now = millis();
  uint8_t validMask = 0;

  bool leftFresh = leftIsFresh(now);
  bool centerFresh = centerIsFresh(now);
  bool rightFresh = rightIsFresh(now);
  bool headingFresh = headingIsFresh(now);

  if (leftFresh)
  {
    validMask |= VALID_LEFT_MASK;
  }

  if (centerFresh)
  {
    validMask |= VALID_CENTER_MASK;
  }

  if (rightFresh)
  {
    validMask |= VALID_RIGHT_MASK;
  }

  if (headingFresh)
  {
    validMask |= VALID_HEADING_MASK;
  }

  int reportedHeading = headingFresh ? heading : INVALID_HEADING;
  int reportedLeft = leftFresh ? distanceLeft : INVALID_DISTANCE;
  int reportedCenter = centerFresh ? distanceCenter : INVALID_DISTANCE;
  int reportedRight = rightFresh ? distanceRight : INVALID_DISTANCE;
  int hardStop = forwardHardStopIsActive(now) ? 1 : 0;
  int signedAppliedSpeed =
    appliedDirection == 0 ? appliedSpeed : -appliedSpeed;

  telemetrySequence++;

  // Protocol:
  // T,seq,ms,heading,left,center,right,validMask,hardStop,appliedSpeed
  Serial.print("T,");
  Serial.print(telemetrySequence);
  Serial.print(",");
  Serial.print(now);
  Serial.print(",");
  Serial.print(reportedHeading);
  Serial.print(",");
  Serial.print(reportedLeft);
  Serial.print(",");
  Serial.print(reportedCenter);
  Serial.print(",");
  Serial.print(reportedRight);
  Serial.print(",");
  Serial.print(validMask);
  Serial.print(",");
  Serial.print(hardStop);
  Serial.print(",");
  Serial.println(signedAppliedSpeed);
}

bool parseIntegerToken(const char *token, int &value)
{
  if (token == NULL || token[0] == '\0')
  {
    return false;
  }

  errno = 0;
  char *endPointer = NULL;
  long parsed = strtol(token, &endPointer, 10);

  if (
    errno == ERANGE ||
    endPointer == token ||
    *endPointer != '\0' ||
    parsed < INT_MIN ||
    parsed > INT_MAX
  )
  {
    return false;
  }

  value = (int)parsed;
  return true;
}

void processCommand(String command)
{
  command.trim();

  if (command.length() == 0)
  {
    return;
  }

  unsigned long now = millis();

  if (command.equalsIgnoreCase("PARKING_OVERRIDE_ON"))
  {
    parkingDistanceOverride = true;
    parkingOverrideLastCommandMillis = now;
    commandReceived = true;
    lastCommandMillis = now;
    stopMotor();
    return;
  }

  if (command.equalsIgnoreCase("PARKING_OVERRIDE_OFF"))
  {
    parkingDistanceOverride = false;
    commandReceived = true;
    lastCommandMillis = now;
    updateHardStopLatch(now);
    stopMotor();
    return;
  }

  // Protocol: speed,direction,steering
  int parts[3] = {0, 0, 0};
  char buffer[100];

  command.toCharArray(buffer, sizeof(buffer));

  char *savePointer = NULL;
  char *token = strtok_r(buffer, ",", &savePointer);

  for (int index = 0; index < 3; index++)
  {
    if (!parseIntegerToken(token, parts[index]))
    {
      return;
    }

    token = strtok_r(NULL, ",", &savePointer);
  }

  // Reject commands with missing or extra fields.
  if (token != NULL)
  {
    return;
  }

  int speedValue = parts[0];
  int direction = parts[1];
  int steeringCorrection = parts[2];

  if (
    speedValue < 0 ||
    speedValue > 255 ||
    (direction != 0 && direction != 1) ||
    steeringCorrection < SERVO_MIN_CORRECTION ||
    steeringCorrection > SERVO_MAX_CORRECTION
  )
  {
    return;
  }

  commandReceived = true;
  lastCommandMillis = now;
  if (parkingDistanceOverride)
  {
    parkingOverrideLastCommandMillis = now;
  }

  updateHardStopLatch(now);
  steer(steeringCorrection);

  if (speedValue == 0)
  {
    stopMotor();
    return;
  }

  if (!headingIsFresh(now))
  {
    stopMotor();
    steer(0);
    return;
  }

  if (direction == 0 && forwardHardStopIsActive(now))
  {
    stopMotor();
    return;
  }

  if (direction == 1 && collisionHardStopLatched)
  {
    reverseReleaseObserved = true;
  }

  driveMotor(speedValue, direction);
}

void receiveCommands()
{
  while (Serial.available())
  {
    char c = Serial.read();

    if (c == '\n')
    {
      commandInput.trim();
      processCommand(commandInput);
      commandInput = "";
    }
    else if (c != '\r')
    {
      if (commandInput.length() < 99)
      {
        commandInput += c;
      }
      else
      {
        commandInput = "";
      }
    }
  }
}

// =====================================================
// Setup
// =====================================================

void setup()
{
  strip.begin();
  strip.setBrightness(80);

  // Turn ON all 6 LEDs - White
  for (int i = 0; i < LED_COUNT; i++)
  {
    strip.setPixelColor(i, strip.Color(255, 255, 255));
  }

  strip.show();

  Serial.begin(115200);
  delay(500);

  pinMode(MOTOR_IN1, OUTPUT);
  pinMode(MOTOR_IN2, OUTPUT);
  pinMode(MOTOR_PWM, OUTPUT);

  stopMotor();

  pinMode(START_BUTTON, INPUT_PULLUP);

  pinMode(SERVO_PIN, OUTPUT);
  digitalWrite(SERVO_PIN, LOW);

  steer(0);

  BaseType_t servoTaskResult = xTaskCreatePinnedToCore(
    servoPulseTask,
    "ServoPulse",
    2048,
    NULL,
    3,
    NULL,
    0
  );

  if (servoTaskResult != pdPASS)
  {
    Serial.println("ERROR: SERVO TASK");

    while (true)
    {
      stopMotor();
      delay(100);
    }
  }

  Wire.begin(I2C_SDA, I2C_SCL);
  Wire.setClock(400000);
  Wire.setTimeOut(20);

  if (!selectMuxChannel(MUX_CH_BNO))
  {
    Serial.println("ERROR: PCA9548A BNO CHANNEL");

    while (true)
    {
      stopMotor();
      delay(100);
    }
  }

  delay(10);

  if (!bno.begin())
  {
    Serial.println("ERROR: BNO055 NOT FOUND");

    while (true)
    {
      stopMotor();
      delay(100);
    }
  }

  delay(1000);
  bno.setExtCrystalUse(true);

  Serial.println("DEBUG: INITIALIZED");

  // Hold the start button for two seconds.
  bool waitingForButton = true;

  while (waitingForButton)
  {
    if (digitalRead(START_BUTTON) == LOW)
    {
      unsigned long pressStart = millis();

      while (digitalRead(START_BUTTON) == LOW)
      {
        if (millis() - pressStart >= 2000)
        {
          waitingForButton = false;
          break;
        }

        delay(1);
      }
    }

    delay(1);
  }

  Serial.println("Waiting for ok");
  waitForOK();
  Serial.println("Handshake Complete");

  lastCommandMillis = millis();
}

// =====================================================
// Main loop — Core 1
// =====================================================

void loop()
{
  // Process commands before sensor polling.
  receiveCommands();

  updateTFLunas();
  updateBNO();

  enforceSafetyInterlocks(millis());

  // Versioned telemetry includes sensor health and applied motor state.
  sendSensorData();

  // Process commands received while sensors were being read.
  receiveCommands();

  enforceSafetyInterlocks(millis());

  delay(20);
}

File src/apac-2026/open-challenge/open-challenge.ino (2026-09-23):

#include <Wire.h>
#include <Adafruit_Sensor.h>
#include <Adafruit_BNO055.h>
#include <utility/imumaths.h>
#include <math.h>

// =====================================================
// Current hardware pins — unchanged
// =====================================================

#define I2C_SDA 21
#define I2C_SCL 22

#define SERVO_PIN 13

#define MOTOR_IN1 25
#define MOTOR_IN2 26
#define MOTOR_PWM 33

#define START_BUTTON 32

// =====================================================
// I2C addresses
// =====================================================

#define PCA9548A_ADDRESS 0x70
#define TFLUNA_ADDRESS   0x10
#define BNO055_ADDRESS   0x28

// =====================================================
// Multiplexer channels — unchanged
// =====================================================

#define MUX_CH_LEFT    0
#define MUX_CH_CENTER  3
#define MUX_CH_RIGHT   2
#define MUX_CH_BNO     4

// =====================================================
// Servo settings
// =====================================================

const int SERVO_CENTER = 106;

const int SERVO_MIN_PULSE_US = 500;
const int SERVO_MAX_PULSE_US = 2400;
const int SERVO_FRAME_MS = 20;

const int FOLLOW_MAX_CORRECTION = 25;
const int TURN_MAX_CORRECTION = 35;

// =====================================================
// Motor speeds — unchanged
// =====================================================

const int DETECTION_SPEED = 190;
const int FOLLOW_SPEED = 190;
const int TURN_SPEED = 160;
const int AFTER_TURN_SPEED = 210;

// =====================================================
// Automatic direction detection
// =====================================================

const int DIRECTION_DETECTION_DISTANCE_CM = 100;
const int DIRECTION_CONFIRMATION_SAMPLES = 3;

// =====================================================
// Wall-following settings
// =====================================================

const float TARGET_LEFT_DISTANCE_CM = 30.0;
const float TARGET_RIGHT_DISTANCE_CM = 30.0;

const int LEFT_OPEN_DISTANCE_CM = 75;
const int RIGHT_OPEN_DISTANCE_CM = 50;

const int LEFT_REACQUIRE_DISTANCE_CM = 50;
const int RIGHT_REACQUIRE_DISTANCE_CM = 50;

const int OPENING_CONFIRMATION_SAMPLES = 3;
const int WALL_CONFIRMATION_SAMPLES = 3;

const unsigned long CLOCKWISE_AFTER_TURN_MS = 500;
const unsigned long ANTICLOCKWISE_AFTER_TURN_MS = 0;

// =====================================================
// Final stopping distance
// =====================================================

const int FINAL_CENTER_DISTANCE_CM = 150;

// =====================================================
// Controller settings
// =====================================================

const float HEADING_KP = 0.55;
const float HEADING_KD = 0.08;

const float WALL_KP = 0.50;
const int MAX_WALL_CORRECTION = 12;

const float TURN_KP = 0.75;
const float TURN_KD = 0.06;

const float TURN_COMPLETE_ERROR = 4.0;

const int TOTAL_TURNS = 12;

const unsigned long CONTROL_PERIOD_US = 10000;

const int INVALID_DISTANCE = 100000;

// =====================================================
// BNO055
// =====================================================

Adafruit_BNO055 bno(
  55,
  BNO055_ADDRESS,
  &Wire
);

// =====================================================
// Direction and robot states
// =====================================================

enum CourseDirection
{
  DIRECTION_UNKNOWN,
  CLOCKWISE,
  ANTICLOCKWISE
};

enum RobotState
{
  WAITING_TO_START,
  DETECTING_DIRECTION,
  FOLLOWING_WALL,
  TURNING,
  WAITING_FOR_WALL,
  WAITING_FOR_CENTER_DISTANCE,
  FINISHED
};

CourseDirection courseDirection = DIRECTION_UNKNOWN;
CourseDirection directionCandidate = DIRECTION_UNKNOWN;

RobotState robotState = WAITING_TO_START;

// =====================================================
// Navigation data
// =====================================================

float targetHeading = 0;

int completedTurns = 0;
int openingSamples = 0;
int wallSamples = 0;
int turnStableSamples = 0;
int directionSamples = 0;

uint8_t consecutiveBnoFailures = 0;

int lastLeftDistance = INVALID_DISTANCE;
int lastCenterDistance = INVALID_DISTANCE;
int lastRightDistance = INVALID_DISTANCE;

unsigned long lastControlUs = 0;
unsigned long afterTurnStartMs = 0;

// =====================================================
// Heading derivative data
// =====================================================

float previousHeadingError = 0;
unsigned long previousHeadingTimeUs = 0;
bool previousHeadingAvailable = false;

// =====================================================
// Shared servo data
// =====================================================

portMUX_TYPE servoMux =
  portMUX_INITIALIZER_UNLOCKED;

volatile uint16_t requestedServoPulseUs = 1500;
volatile int requestedServoAngle = SERVO_CENTER;

// =====================================================
// Servo functions
// =====================================================

uint16_t angleToPulse(int angle)
{
  angle = constrain(angle, 0, 180);

  return (uint16_t)map(
    angle,
    0,
    180,
    SERVO_MIN_PULSE_US,
    SERVO_MAX_PULSE_US
  );
}

void commandServoCorrection(
  int correction,
  int maximumCorrection
)
{
  correction = constrain(
    correction,
    -maximumCorrection,
    maximumCorrection
  );

  int angle = SERVO_CENTER + correction;
  angle = constrain(angle, 0, 180);

  uint16_t pulse = angleToPulse(angle);

  portENTER_CRITICAL(&servoMux);

  requestedServoAngle = angle;
  requestedServoPulseUs = pulse;

  portEXIT_CRITICAL(&servoMux);
}

void centerSteering()
{
  commandServoCorrection(
    0,
    TURN_MAX_CORRECTION
  );
}

// =====================================================
// Dedicated servo task — Core 0
// =====================================================

void servoPulseTask(void *parameter)
{
  TickType_t lastWakeTime =
    xTaskGetTickCount();

  const TickType_t framePeriod =
    pdMS_TO_TICKS(SERVO_FRAME_MS);

  while (true)
  {
    uint16_t pulseWidth;

    portENTER_CRITICAL(&servoMux);
    pulseWidth = requestedServoPulseUs;
    portEXIT_CRITICAL(&servoMux);

    digitalWrite(SERVO_PIN, HIGH);
    delayMicroseconds(pulseWidth);
    digitalWrite(SERVO_PIN, LOW);

    vTaskDelayUntil(
      &lastWakeTime,
      framePeriod
    );
  }
}

// =====================================================
// PCA9548A multiplexer
// =====================================================

bool selectMuxChannel(uint8_t channel)
{
  if (channel > 7)
  {
    return false;
  }

  Wire.beginTransmission(PCA9548A_ADDRESS);
  Wire.write(1 << channel);

  return Wire.endTransmission() == 0;
}

// =====================================================
// TF-Luna functions
// =====================================================
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

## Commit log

2026-07-19 vision: pillar detection v4.1 - dual classifier with startup auto-select
    pillar_fast.py: cv2-HSV and fused 32^3 LUT classifiers, per-machine auto-bench picks winner at startup; Pi5 120fps capture path (IMX708 1536x864 sensor mode, RGB888 lores, zero-copy capture_request). pillar_ab.py: same-frame A/B harness with live timings. bench_*: classify variant shootout, no-camera pipeline ceiling (~2300fps on 7700X), ordering-artifact falsification. Key finding: 3x3 open shields CCL from speckle - LUT path +65% cost on worst-case noise, so auto-select benches on worst-case input deliberately.
    [bench_classify.py, bench_full.py, bench_order.py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]
2026-07-26 Round 2: add trained pillar detector + move vision under Round 2
    Adds src/Round 2/detector/ - the Obstacle Challenge pillar detector that
    outputs the pass side (red -> right, green -> left).
    Model: NanoDet-Plus stripped to 45 files (no Lightning/yacs/pycocotools),
    trained from scratch on a leakage-free group-wise split of 597 real images
    plus mined background negatives and composited both-pillar frames.
    val macro F1 0.834 -> 0.898 (vs the 111K baseline)
    pass-side decision accuracy 0.879 -> 0.941
    wrong side, both pillars 31.7% -> 13.3%
    false det per empty frame 0.283 -> 0.083
    Deploy artifact is models/pillar_nanodet320.onnx (4.52 MB, 1,167,660 params,
    fixed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
    [bench_classify.py, bench_full.py, bench_order.py]
2026-07-28 docs: add criterion-aligned engineering documentation set
    Adds docs/1_mobility, 2_power_and_sensors, 3_software,
    4_systems_and_decisions, 5_reproducibility and tests.md.
    The substantive addition is the decision log in 4_: five decisions that were
    made, measured and in two cases reversed - the HSV-to-neural reversal, the
    tiny_pillar vs nanodet_lite head-to-head, the rejected HSV rescoring, a
    falsified parameter-count prediction, and the leakage audit that invalidated
    and rebuilt our own validation split. Each keeps the rejected alternative
    described rather than deleted.
    Also adds a ten-entry risk register with mitigation state, the camera-placement
    geometry derived from pillar dimensions, a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
2026-07-28 docs: rewrite root README around the five scoring criteria
    The previous README described the vehicle as camera-free and listed vision as
    the single biggest open item. That stopped being true when the trained detector
    landed on this branch, so the claim is removed.
    Replaces the seven-section layout with a numeric summary, a
    criterion-to-document index, a competition-artifact status table, a version
    history carrying the problem each stage exposed, and an explicit known-limits
    section. 5491 -> 7196 characters.
2026-07-28 docs: replace directory placeholders with artifact status and blockers
    Four mandated directories still carried the unedited WRO template text, which
    says what must go there and nothing about whether it does. Each now states the
    requirement, the current status, the blocker, and where the reasoning lives.
    Also fixes src/README.md, which still referenced
    IMU_STRAIGHTLINE_SERVO_DISTANCE.ino at the top of src/ - that file was renamed
    to round 1.ino and moved under Round 1/ on 2026-06-26, and the Round 2
    perception tree was missing from the table entirely.
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2026-08-05 docs(schemes): add signal-wiring schematic v0.1 (PNG + PDF)
    Fixed signal wiring: ESP32, PCA9548A, 3x TF-Luna, BNO055, servo, TB6612/N20,
    Pi 5 serial link, USB camera. Power tree deliberately not drawn - pending
    battery selection. BNO drawn on mux CH4; the CH5 discrepancy in off-repo
    Round 2 code is flagged on the diagram and in the README.
2026-08-05 docs: align repo with field state - picker stack of record, drive chosen
    - Calibrated-Lab colour picker declared the Round 2 stack of record;
    nanodet_lite superseded after field transfer failure, kept as evidence
    (status banner + D6 decision entry with the reversal reasoning).
    - Drive motor recorded as chosen and integrated (N20 via TB6612); mobility
    doc gains the drive section; unchosen set narrowed to the working point.
    - Camera identity closed: USB UVC webcam (model pending); CSI path gated.
    - Obstacle Challenge status: implemented off-repo, landing after
    integration fixes (rule 11.10 radio removal, I2C map, STBY).
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2026-08-06 feat: Round 2 stack lands - calibrated-Lab picker runtime + ESP32 controller
    Committed verbatim as field-run source. Known issues from the 2026-08-06 review (BT removal per 11.10, STBY, IMU mode, REVERSE handling, PARK states per D7, wait-for-start per 9.11) are queued for the pre-snapshot patch.
    [main.cpp, round2.py]
2026-08-07 fix: Round 2 hardening - state-gated protocol, wait-for-start, IMUPLUS, gradient visual steering, headless runtime
    cpp A1-A13: mux ch4; STBY driven high; Bluetooth behind compile flag (default off, rule 11.10); WAIT_FOR_START on BOOT button with heading captured at press (rules 9.6-9.14); IMUPLUS + turn targets stepped from previous target (cardinal snap deleted); state-gated parse (mid-avoid color switch now flips the swerve, TURNING/STOPPED ignore detections); REVERSE handler using BACKWARD_SPEED, exits back to AVOIDING; dead-man 1500ms; gradient visual steering from the Pi POS stream with full-lock as saturation clamp and no-data fallback; 5-loop direction-consistent spike persistence; ra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
    [main.cpp, round2.py]
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2026-08-07 docs: reconcile 3_software with the landed Round 2 stack
    Section 2 now documents the flashed controller: six-state machine (WAIT_FOR_START through ROBOT_STOPPED), state-gated five-message serial protocol with 0.5s keepalive and 1.5s dead-man, gradient avoidance with full-lock as saturation clamp, start-button heading capture, IMUPLUS + previous-target 90-degree stepping, 5-loop spike persistence. Kills the stale conf>=0.45 transition (the calibrated picker has no confidence scalar; the gate is the 5-of-7 vote + height band + pass-side line). Fixes 3-of-5 -> 5-of-7 and the off-repo runtime line. Parking states marked designed-not-yet-implemented.
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2026-08-09 docs: add Round 2 development history and 2026-08-05 bench photographs
    Adds src/Round 2/history/ with the earlier and parallel Round 2 sources, grouped
    into their three lineages and documented in a README: the colour-picker
    ancestors that the shipped round2.py descends from, the superseded ONNX/NanoDet
    runtimes including the ESP-wired variant, and camera.py, which combines colour
    segmentation with a shape test and a confidence score. Keeping the versions that
    did not work is deliberate - the reasons each was replaced are the content of
    the iteration cycles in docs/4_systems_and_decisions.md, and a repository
    showing only the final file hides the engineering.
    camera.py's is_pillar_shaped tes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
    [capture.py, detect.py, detect_2026.py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]
2026-08-09 docs: add 2026-08-09 drive-speed test runs and failure timeline
    Two recordings from the same day on the Obstacle Challenge mat, at motor speed
    400 and 700, with a README documenting the failing run frame by frame.
    At 400 the vehicle runs for the full 50 s recording without intervention. At 700
    it completes leg 1 cleanly, executes the first turn, then continues past the new
    leg heading and strikes the inner block about 1.1 s later.
    The useful measurement is the implied angle rather than the crash itself. The
    corridor is 1000 mm wide, so from mid-corridor there is roughly 500 mm of lateral
    margin; losing it in 1.1 s implies a post-turn heading error around 30-40
    degrees. A steering loop with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
2026-08-09 docs: add 2026-08-08 test runs; record firmware-revision status per run
    Adds other/test-runs-2026-08-08/ with two runs recorded a minute apart, one that
    wobbles and strikes the wall at the first turn and one that moves at roughly
    0.2 m/s while correcting its steering continuously without ever settling.
    These two are different software revisions from each other and from the
    2026-08-09 pair, so the README states plainly that nothing in that folder can be
    compared against anything else and that the revision behind each run is still
    outstanding from the team.
    The 2026-08-09 README is amended in the opposite direction: both runs there
    shared one firmware revision with only the speed setting cha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
2026-08-09 fix(round1): correct steering-correction sign; retune servo geometry and drive speed
    Steering correction was SERVO_CENTER + STEER_GAIN * error, which drove the heading error open instead of closed. Now subtracts. Alongside: SERVO_CENTER 90->106 with asymmetric limits 64/136, STEER_GAIN 1.5->1, new 2.0 deg deadband, DRIVE_SPEED 550->1000, FINAL_RUN_MS 1500->500. Side LiDARs are muted for 1 s after a corner so one opening cannot re-trigger; heading and steering stay live during the mute. Adds per-loop [steer] telemetry. Start-button block present but commented out and not yet correct.
    [round 1.ino]
2026-08-10 docs(schemes): wiring v0.2 - power tree drawn; TBDs and missing switch/fuse on-sheet; generator committed
    Supersedes v0.1's deliberately undrawn power tree. Buck photo-identified 2026-08-10: dual-rail, barrel-jack in, 5V screw + USB-A out, chip/rating TBD. Servo drawn as-wired through the ESP32 5V chain per docs/2; the buck's USB-A drawn as the CANDIDATE Pi 5 supply (TBD - no PD, 600 mA USB-peripheral cap). N20 rated voltage, buck rating, Pi supply path and camera model drawn as TBD rather than guessed. Missing rule-9.10 main power switch and absent fuse called out on-sheet. v0.1's CH4-vs-CH5 note resolved by Round 2 firmware landing on CH4; v0.1 retained as history. Diagram is generated by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
    [make_wiring_v0_2.py]
2026-08-10 docs: chassis rebuild CANCELLED - current chassis is FINAL; R10 rewritten on 08-09 run evidence
    R10 and 1_mobility both promised a 3D-printed chassis rebuild in fabrication; per the team 2026-08-10 the rebuild is cancelled and the existing frame is final. Both superseded in place. Evidence downgrading the risk is already committed: the two 2026-08-09 Round-1 runs are 28 s and 29 s of continuous driving with no wheel loss, ~6x the 2026-08-06 failure duration. How retention was resolved is not recorded - stated as such. Residual gates: one full three-lap run + the wall-strike stall case. Committable-CAD scope narrows to the printed mounts (3x TF-Luna, servo, N20). Also: schematic v0.2 data-lin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
    [make_wiring_v0_2.py]
2026-08-10 fix(round2): align servo center/limits to the mat-tuned linkage; center the servo-angle init
    SERVO_CENTER 100 -> 106 and symmetric SERVO_CENTER +/- DIFF(35) replaced with the real asymmetric window 64/136 (matches Round 1's 58adb1c tune; same physical linkage, chassis final per team 2026-08-10). The symmetric form could not express the window: 106+35 = 141 would command the servo past the 136 linkage stop. DIFF kept at 42 as the visual-swerve cap with the per-side constrain truncating the shorter (+30) side. finalServoAngle now initialises at SERVO_CENTER instead of 90. NOT yet mat-tested at these values - bench-verify steering direction and center before flashing.
    [main.cpp]
2026-08-10 docs: repo-wide consistency pass against the 2026-08-10 tree
    Root README: obstacle stack marked in-repo (was 'implemented off-repo' in 3 places), steering row updated to the 58adb1c tune (64-136/106, gain 1.0+deadband; was 45-135/1.5), drivetrain/chassis rows reflect the cancelled rebuild, schematic row Present (v0.2), video row states the real bar, honest-limits bullets superseded in place (controller landed, camera = OMO/WCAM/11, bring-up done). src/README: Round 2 table now lists the flight stack (round2.py/main.cpp/eval_picker/history), off-repo paragraph struck, run-on 1.5s->0.5s, dead 3_software anchor fixed. 1_mobility: steering + drive tables updated to 58adb1c (retunes dated, old va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
    [eval_picker.py, make_wiring_v0_2.py, round 1.ino]
2026-08-10 docs(3_software): Open-Challenge control-law paragraph updated to the 58adb1c tune
    Missed in the 5f199fc consistency pass: step 2 still described gain 1.5 clamped 45-135. Now 1.0 gain + 2.0 deg deadband, 64-136 asymmetric about the 106 centre, retune dated.
2026-08-10 docs+tools: TED drive lands on the README + journal cover; README ToC; serial run logger
    Team name confirmed by the team 2026-08-10: TED drive. README header TBDs filled (members Ethan Fernandes / Tejas Sirikonda / Diaan, coach Amey Chavan, OMOTEC) and a one-line Contents index added - the README had 8 sections and no ToC. Journal cover: team name + Tejas's surname filled (2 of the Appendix-B checklist items); the rest of the checklist stays yellow on purpose. tools/serial_log.py: timestamped host-side capture of the ESP32 telemetry - the instrument for the still-missing logged run (loop rate, [turn] n/12, run-on timing all fall out of one capture); logs/ is created at runtime and stays untr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
    [serial_log.py]
2026-08-10 docs(journal): truth pass against the 2026-08-10 tree
    13 edits from tonight's audit, placeholders left intact. Chassis-rebuild narrative superseded in 4 places (2.3 fix paragraph + evidence sentence in the old status slot, D8 decision bullet rewritten as decided-then-cancelled-on-evidence, ch6 models line, BoM chassis row) - the journal now tells the true arc: rebuild drafted, existing frame survived ~6x the failure duration across the 08-09 runs, rebuild cancelled, frame final. Steering 2.2 -> 106 / 64-136 asymmetric (Round-1 mat tune). Camera -> OMO/WCAM/11 in 3.5 + BoM. 3.1 switch/button rewritten honestly: R2 waits, R1 wait-for-start written and bench-pending, the power switch is NOT yet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
2026-08-10 feat(round1): wait-for-start on GPIO0 (rule 9.11) - BENCH TEST PENDING, do not merge to main until verified
    Round 1 on main auto-starts after a 1.5 s delay - a live 9.11 violation at the judging table. This adds waitForStart(): INPUT_PULLUP on GPIO0 (the onboard BOOT button, matching Round 2's START_BUTTON_PIN), block for press, 50 ms debounce, block for release, THEN captureReference() - so the heading reference is now captured at the start press with the car placed on the mat, matching the journal's 3.1 description. The old commented-out GPIO32 block is removed: it was buggy (btn never reassigned inside its loop -> would hang forever). GPIO0 is a strap pin, which motor_control.h advises ag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
    [round 1.ino]
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2026-08-11 docs(power): datasheet-derived predicted budget; measured column empty by design
    Predictions exist to give the multimeter session sanity bands, not to replace it. Sources cited per component. Two on-vehicle discrepancies this file forced: pack label 2200 not 2600, and the reworked servo-power topology - both corrected in 2_power_and_sensors in this push.
2026-08-11 feat(round2): controller+vision v2 - LAB-u8 LUT, logging stack, GPIO32 start
    v1: by-id serial hard-fail (headless exit 2), lunaValid 2-600cm, stop-check gated to DRIVING_STRAIGHT (restores docs), corner detection armed during OBSTACLE_AVOIDING [MAT-UNVERIFIED], stale-POS decay + blind-lock bound [MAT-UNVERIFIED], POS validation, [TX]/[ESP]/[calib]/[perf]/[turn]/[stop] logging. v2: cv2-LAB u8 LUT masks (parity IoU .97/.99/.98 vs float path, 3.3x faster), legacy calib.json auto-migration, per-color KV thresholds, gated FAST tier (kill: FAST=STRAIGHT), esp_task_wdt 3s dual-API, lunaMedian3, [drift] 1Hz in wait, magenta parking FOUNDATION (logs only, drives nothing). START_BUTTON_PIN 32 external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
    [main.cpp, round2.py]
2026-08-11 docs: reconcile hardware truths read off vehicle 2026-08-11
    Pack label re-read: 2200mAh 60C (2026-08-06 note said 2600 - misread). Power tree as built: Pi via fast-charge module, ESP32 from Pi USB, Buck-2 feeds 3x Luna + servo POWER (signal from ESP32) - the sec-5 servo-chain failure point is FIXED by rework, row updated. Wait-for-start now exists on GPIO32 external button; still NO main power switch (power-on = battery plug) - inline rocker planned, rule 9.6/9.10. 1_mobility: drivetrain 20T:28T on LEGO diff 62821 = 5:7, wheels ~71% motor speed (teeth counted); battery row corrected. 3_software: OBSTACLE_AVOIDING->TURNING edge added (MAT-UNVERIFIED). src/README: serial by-id line.
2026-08-11 fix(round1): start button GPIO0 -> GPIO32 (matches physical wiring) - bench pending
    The external button is wired to GPIO32 - the pin the old commented block polled all along. GPIO0 was an interim strap-pin choice; superseded.
    [round 1.ino]
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2026-08-12 docs: consistency sweep - pinion:crown 20:28 landed everywhere, models/ and video rows current, rebuild-cancelled table row fixed, schemes power tree marked historical (2200 mAh label read), GPIO32 d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
2026-08-12 docs: consistency sweep - one dated truth per fact across the repo
    Zeroes the 11 live contradictions found in the 2026-08-12 audit:
    - pack capacity: 2200 mAh 60C everywhere current; "2600" survives only
    inside dated correction notes and the frozen wiring-v0.2 historical
    artifact (script bannered HISTORICAL, deliberately byte-reproducible)
    - camera: Lenovo 300 FHD per the 2026-08-11 unit read; OMO/WCAM/11 kept
    as the team's designation for the same unit (was briefly carried as
    the model name)
    - 1_mobility: gearing CLOSED (20T:28T counted 08-11), no-load ceiling
    closed at ~1.15 m/s, chassis row superseded in place (rebuild
    cancelled 08-10), models/ paragraph reflects the committed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
    [eval_picker.py, make_wiring_v0_2.py]
2026-08-12 docs: magenta as a third calibrated class; controller as-committed
    3_software: the state-machine status says as-committed rather than as-flashed,
    and states that a flash precedes any run with the revision recorded in the run
    log. New 3.1 documents the magenta gates (b* < 126 pre-gate, chroma floor 32,
    OPEN 3x3, extent 0.40 / top-3 / aspect 8, max_tol 22). New 4.2 gives the
    validation: 43/85 -> 76/85 at tolerance 20 on 85 mat frames, with the nine
    residual misses decomposed as close-approach chroma collapse. Edge-case row
    and strategy-history row updated.
    4_systems: D7's first constraint is closed - bay detection exists, the park
    controller does not. R3 mitigation now cites the measured sepa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
    [main.cpp, round2.py]
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2026-08-12 feat(detector): commit magenta measurement raws - 85 mat frames + 132 labels, analysis tools, 3-class training notebook
    The 46.8-55.1 (a,b) separation and the 43/85 -> 76/85 detection figures in
    3_software were previously unbacked by committed data. The frames that produced
    them are now in the repo, with the extraction and measurement scripts, so a
    reader can recompute rather than trust.
    Limits stated in the folder README: one session, one phone, AWB drift a* 60->49
    across the two clips, 9 residual misses all close-approach chroma collapse
    (forward-Luna regime by design). Venue calibration remains the race procedure.
    Hue augmentation deliberately disabled (hue is the class label); split is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
2026-08-12 docs(power): per-rail current derivation - the arithmetic chain behind the predicted bands
    Rows 5-7 stated current bands without showing how nine sourced component
    figures become a pack current. Adds the derivation per rail (Buck-2, Pi
    module, TB6612/N20), the I_pack = P/(eta x V) conversion with eta stated as
    the single unsourced assumption, and a roll-up that reproduces rows 5-7 within
    their bands - so the numbers can be checked, not trusted.
    Four design consequences fall out: 25-37 runs per charge (endurance is not a
    constraint); peak draw is 2.0% of the 60C rating, so any measured sag
    implicates the harness and never the cells; Buck-2 must be sized to the 1.25 A
    servo transient rather t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
2026-08-12 feat(round2/park): shimmy parallel-park controller - WRITTEN, NEVER RUN
    Implements the team-specified manoeuvre: confirm the bay from the Pi MAG
    stream, run a short distance past it, then alternate reverse-into-bay and
    forward-counter-steer legs until both side rangefinders read short.
    Design notes worth keeping:
    - Legs terminate on BNO055 heading delta, not elapsed time, because timing
    drifts with pack voltage and the IMU does not. Time caps remain as a
    backstop only.
    - THE BINDING CONSTRAINT IS THAT THERE IS NO REAR SENSOR. All three
    TF-Lunas face left/centre/right, so every reverse leg is blind and
    dead-reckoned. That is why the reverse cap is short, the angle step is
    small an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
    [park_shimmy.h]
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2026-08-19 feat(detector): 3-class yolo26n v2 weights + ONNX, training/eval harness, Pi capture tool
    Retrained on the 2,873-frame gate_v2 dataset (3,501 boxes).
    Val mAP50-95 0.980 (green .989 / red .963 / magenta .988), 715 held-out images.
    Blind gold set 41/41: 100% recall, 100% precision, 0 class swaps, 0 FPs.
    Class map unchanged: 0=green 1=red 2=magenta. ONNX output (1,300,6) end2end,
    identical layout to the deployed model, so detect_3class.py runs it unchanged.
    Reproducible: three runs bit-identical, 708/708 tensors, max abs diff 0.
    Adds tools/wro_capture.py (Pi capture rig) and the yolo26n train/eval scripts.
    [wro_capture.py]
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2026-08-20 fix(round2): bound the bay-exit reverse leg by the forward leg it follows
    Found on a re-check of the parking-bay shuffle.
    The vehicle starts with its rear flush against the back magenta wall, so
    the only clearance behind it is whatever the preceding forward leg just
    created. The reverse leg was capped by a fixed EXIT_REV_MS instead, which
    is only safe while the forward leg runs its full duration. It does not:
    it exits early on the heading gate, and on the front-wall guard. Whenever
    that happened the reverse leg travelled further than the forward leg had,
    and drove the rear into the wall it started against.
    The reverse is now capped at EXIT_REV_FRAC (0.85) of the forward leg's
    measured runt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
    [round2_ino.ino]
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2026-09-22 feat(apac): add the parking modules (parallel and direct entry) as standalone scripts
    src/apac-2026/obstacle-challenge/parallel_parking.py (slot-guided-entry-v29, MD5 6e8112e6) and partial_parking.py (direct entry, MD5 7e4ef164), stored byte-for-byte. main.py as committed does not call them (ENABLE_PARKING_IN = False); both import main.py and need parking_camera_calibration.json, made on the vehicle with --calibrate. docs/apac_2026_software.md: new section 8 (detection, states, partial differences, reasons from the code comments, failure exits), parking logs in section 7, four known limits in section 6. src/apac-2026/README.md: files, settings, calibration note, provenance, MD5s.
    [parallel_parking.py, partial_parking.py]
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2026-09-22 feat(apac): main.py updated to the 2026-09-18 version the car runs, with its changes documented
    src/apac-2026/obstacle-challenge/main.py: replaced byte-for-byte by the version dated 2026-09-18 (MD5 9b7eb750d26e9df2448196452a0b5cbe) from the team's Google Drive; cmd.txt there starts final-code/obstacle-challenge-final-code/main.py. v0.4.0's file (MD5 238dd1af) stays in the history. Firmware unchanged (byte-identical).
    docs/apac_2026_software.md: scope (s1-s6 = v0.4.0), new s10 (walls: PILLAR_RECENTER, ROUND2 recentre, corner-clearance recovery; corner zone lock, pre/post-turn states; two pillars per straight, central view, parking-lot rule; parking-in chain; run CSV log; table of superseded v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
    [main.py]
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
